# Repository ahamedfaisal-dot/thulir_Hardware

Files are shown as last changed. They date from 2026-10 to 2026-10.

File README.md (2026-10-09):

# THULIR — 3-Stage Cascaded Peltier Temperature Controller

Production-quality firmware for ESP32-S3 driving three cascaded Peltier modules via BTS7960 H-bridge drivers with PID control, TFT HMI, keypad programming, voice announcements, dual servo motors, and comprehensive safety. Cold-side sensing is an I2C SHT3x (temperature + humidity).A companion Python Flask web dashboard streams live telemetry, logs to Excel, and runs on-device ML predictions for seed viability and storage life extension.

---

## Table of Contents

1. [System Architecture](#system-architecture)
2. [Wiring Tables](#wiring-tables)
3. [Power Wiring](#power-wiring)
4. [GPIO Pin Map](#gpio-pin-map)
5. [Required Libraries](#required-libraries)
6. [File Structure](#file-structure)
7. [Process Flow](#process-flow)
8. [PID Tuning Guide](#pid-tuning-guide)
9. [Commissioning Procedure](#commissioning-procedure)
10. [Troubleshooting](#troubleshooting)
11. [Safety Notices](#safety-notices)
12. [Web Dashboard &amp; Seed Intelligence](#web-dashboard--seed-intelligence)

---

## System Architecture

```
┌───────────────────────────────────────────────────────────────────┐
│                         ESP32-S3                                   │
│                                                                    │
│  ┌──────────┐  ┌──────────┐  ┌──────────┐  ┌──────────┐          │
│  │ PID      │  │ Temp     │  │ Recipe   │  │ Safety   │          │
│  │Controller│  │ Manager  │  │ Manager  │  │ Manager  │          │
│  └─────┬────┘  └─────┬────┘  └──────────┘  └─────┬────┘          │
│        │              │                           │                │
│  ┌─────▼────────────────────────────────────────────────┐         │
│  │              Main State Machine                       │         │
│  │   BOOT → IDLE → APPROACH → HOLD → RAMP → COMPLETE   │         │
│  └─────┬────────────────────────────────┬────────┬──────┘         │
│        │                                │        │                 │
│  ┌─────▼────┐  ┌──────────┐  ┌────────▼──┐  ┌──▼──────┐         │
│  │ Peltier  │  │ Display  │  │ Keypad    │  │ Audio   │          │
│  │ Control  │  │ Manager  │  │ Manager   │  │ Manager │          │
│  └─────┬────┘  └─────┬────┘  └─────┬─────┘  └────┬────┘         │
└────────┼──────────────┼─────────────┼──────────────┼──────────────┘
         │              │             │              │
    ┌────▼────┐   ┌─────▼────┐  ┌────▼────┐  ┌─────▼────┐
    │ 3×      │   │ ILI9341  │  │ 4×4     │  │ DFPlayer │
    │ BTS7960 │   │ 320×240  │  │ Keypad  │  │ Mini     │
    └────┬────┘   └──────────┘  └─────────┘  └──────────┘
         │
    ┌────▼────────────────┐
    │ 3× Peltier Modules  │
    │ (Cascaded Stack)    │
    │ BOT → MID → TOP    │
    └─────────────────────┘
```

---

## Wiring Tables

> The table below is the **authoritative, verified-working** pinout as of the
> final hardware bring-up (TFT confirmed working via `Adafruit_ILI9341`).
> It matches `Config.h` exactly — if the two ever disagree, trust `Config.h`
> and update this table.

### Low-Current Logic Connections (3.3V / Signal Level)

| Component | Component Pin | ESP32-S3 GPIO | Notes |
| --- | --- | --- | --- |
| **BTS7960 #1 (Bottom)** | RPWM | GPIO 4 | PWM signal |
| | LPWM | **GND** (hardwired)  | Always LOW — wire directly to GND; no GPIO used |
| | R_EN | **3.3V** (hardwired) | Always HIGH — wire directly to 3.3V; no GPIO used |
| | L_EN | **3.3V** (hardwired) | Always HIGH — wire directly to 3.3V; no GPIO used |
| | VCC | 3.3V | Logic supply |
| | GND | GND | Common ground |
| **BTS7960 #2 (Middle)** | RPWM | GPIO 8 | PWM signal |
| | LPWM | **GND** (hardwired)  | Always LOW — wire directly to GND; no GPIO used |
| | R_EN | **3.3V** (hardwired) | Always HIGH — wire directly to 3.3V; no GPIO used |
| | L_EN | **3.3V** (hardwired) | Always HIGH — wire directly to 3.3V; no GPIO used |
| | VCC | 3.3V | Logic supply |
| | GND | GND | Common ground |
| **BTS7960 #3 (Top)** | RPWM | **GPIO 42** | PWM signal (moved from GPIO12 to free native FSPI SCK) |
| | LPWM | **GND** (hardwired)  | Always LOW — wire directly to GND; no GPIO used |
| | R_EN | **3.3V** (hardwired) | Always HIGH — wire directly to 3.3V; no GPIO used |
| | L_EN | **3.3V** (hardwired) | Always HIGH — wire directly to 3.3V; no GPIO used |
| | VCC | 3.3V | Logic supply |
| | GND | GND | Common ground |
| **SHT3x (Cold side, Temp+Humidity)** | VIN | 3.3V | 2.2–5.5V tolerant sensor, powered at 3.3V here |
| | GND | GND | |
| | SDA | **GPIO 35** | GPIO3 (strapping pin, broke uploads) and GPIO33 (not broken out on this board) were tried first |
| | SCL | **GPIO 36** | Confirmed present and free on this board's actual pinout diagram |
| **DS18B20 (Hot side, optional)** | DATA | GPIO 37 | Not installed by default — set`HOT_SIDE_SENSOR_ENABLED true` in Config.h to use. Moved from GPIO43 — OneWire hung the chip on that pin (ESP32-S3's default UART0 pin) |
| | VCC | 3.3V | |
| | GND | GND | |
| **TFT ILI9341** | SCK | **GPIO 12** | Driven via`Adafruit_ILI9341` + explicit `SPIClass(FSPI)` |
| | MOSI (SDI) | **GPIO 11** | |
| | MISO (SDO) | **GPIO 13** | Used for panel ID readback during bring-up diagnostics |
| | CS | **GPIO 10** | Chip select |
| | DC | **GPIO 9** | Data/Command |
| | RST | **GPIO 14** | Reset |
| | VCC | **5V** | This module needs 5V — 3.3V leaves the onboard regulator without enough headroom to init |
| | GND | GND | |
| | LED | 3.3V | Backlight (always on) |
| **4×4 Keypad** | ROW0 | GPIO 16 | |
| | ROW1 | GPIO 17 | |
| | ROW2 | GPIO 18 | |
| | ROW3 | GPIO 38 | (Moved from 19 — USB) |
| | COL0 | GPIO 20 | |
| | COL1 | GPIO 39 | |
| | COL2 | GPIO 40 | |
| | COL3 | GPIO 41 | |
| **DFPlayer Mini** | RX | GPIO 1 (ESP TX) | 1kΩ series resistor recommended |
| | TX | GPIO 2 (ESP RX) | |
| | VCC | 5V | |
| | GND | GND | |
| **Servo 1** | Signal | GPIO 22 | LEDC ch 3, 50 Hz PWM, 500–2400 µs pulse width |
| | VCC | **5V** | Hobby servos (SG90/MG90S) require 5V — do**not** use 3.3V |
| | GND | GND | |
| **Servo 2** | Signal | GPIO 23 | LEDC ch 4, 50 Hz PWM, 500–2400 µs pulse width |
| | VCC | **5V** | Shared 5V rail with Servo 1 |
| | GND | GND | |

> **BTS7960 LPWM / R_EN / L_EN — all three hardwired (actual build):**
> All six enable/direction pins across the three BTS7960 boards are directly
> wired to fixed rails — no GPIO is used for them:
>
> - **LPWM** → GND (always LOW, enforces unidirectional cooling)
> - **R_EN** → 3.3V (always enabled)
> - **L_EN** → 3.3V (always enabled)
>   Only the three **RPWM** lines (GPIO 4, 8, 42) are controlled by the
>   ESP32. This matches `Config.h` which has no LPWM/R_EN/L_EN `#define`s
>   for these hardwired pins.

### High-Current Power Connections (12V)

| Connection | Wire Gauge | Fuse | Notes |
| --- | --- | --- | --- |
| SMPS 12V → BTS7960#1 B+ | ≥14 AWG | 15A blade | Bottom Peltier (12A max) |
| BTS7960#1 M+ → Bottom Peltier + | ≥14 AWG | — | Observe polarity! |
| BTS7960#1 M− → Bottom Peltier − | ≥14 AWG | — | |
| SMPS 12V → BTS7960#2 B+ | ≥16 AWG | 10A blade | Middle Peltier (6A max)  |
| BTS7960#2 M+ → Middle Peltier + | ≥16 AWG | — | |
| BTS7960#2 M− → Middle Peltier − | ≥16 AWG | — | |
| SMPS 12V → BTS7960#3 B+ | ≥16 AWG | 10A blade | Top Peltier (6A max) |
| BTS7960#3 M+ → Top Peltier + | ≥16 AWG | — | |
| BTS7960#3 M− → Top Peltier − | ≥16 AWG | — | |
| SMPS 12V → 4× Fans | ≥16 AWG | 5A | Hardwired, always on |
| SMPS GND → All BTS7960 B− | ≥12 AWG | — | Star ground recommended  |

---

## Power Wiring

```
12V 30A SMPS
     │
     ├──── [15A Fuse] ──── BTS7960 #1 B+/B− ──── Bottom Peltier (12V/12A)
     │
     ├──── [10A Fuse] ──── BTS7960 #2 B+/B− ──── Middle Peltier (12V/6A)
     │
     ├──── [10A Fuse] ──── BTS7960 #3 B+/B− ──── Top Peltier   (12V/6A)
     │
     ├──── [5A Fuse]  ──── 4× Cooling Fans (hardwired)
     │
     └──── 12V→5V Buck ──── ESP32-S3 5V input
            Converter        (or use USB-C for dev)

    ⚠ CRITICAL GROUND RULES:
    • All BTS7960 B− terminals connect to SMPS GND
    • All BTS7960 logic GND pins connect to ESP32 GND
    • ESP32 GND must have a common reference with SMPS GND
    • Use a star-ground topology to minimize ground loops
    • NEVER route 12V/12A through signal-level PCB traces
```

---

## GPIO Pin Map

See `Config.h` for the authoritative, editable pin definitions.

**ESP32-S3 Pins to Avoid:**

- GPIO 0: Boot strapping pin (download mode) — avoid pull-ups/downs
- GPIO 3: Boot strapping pin (JTAG signal source) — **learned the hard
  way**: this was originally used for the SHT3x's I2C SDA, and its
  external pull-up resistor altered this pin's strap state on every
  reset, breaking `esptool`'s USB download-mode handshake entirely
  ("Wrong boot mode detected (0x4)", uploads failed completely). Avoid
  any pull-up/pull-down on GPIO3.
- GPIO 19: USB D− on DevKitC-1
- GPIO 26–32: Do not exist on ESP32-S3 (internal flash)
- GPIO 33, 34: **Not broken out at all on this ESP32-S3-DevKitC-1 board**
  (confirmed from the board's own pinout diagram — these two pins simply
  don't appear on the header). This module reserves them internally for
  PSRAM. Also tried and abandoned for the SHT3x before settling on 35/36.
- GPIO 35–37: Present on this board's header and genuinely free — the
  fact that the board omits 33/34 but keeps 35-37 confirms this module
  only needs 33/34 for PSRAM. **This firmware uses GPIO 35/36 for the
  SHT3x's SDA/SCL, and GPIO 37 for the optional hot-side DS18B20.**
- GPIO 43, 44: Default UART0 TX/RX. With **USB Mode: "Hardware CDC and
  JTAG"** (as specified below), `Serial` runs over native USB instead of
  UART0, and GPIO44 works fine as a plain GPIO output (used here for
  BTS7960 #3 R_EN) — but **GPIO43 hung the chip when OneWire tried to
  use it** during hot-side sensor bring-up (see `DS18B20_Test/`), likely
  because the ESP32-S3 boot ROM itself still drives GPIO43 for its own
  UART0 boot-log output before the app takes over, regardless of the
  USB Mode setting. Avoid GPIO43 for anything timing-sensitive; the
  optional hot-side sensor now uses GPIO37 instead.
- GPIO 45: Boot strapping pin (VDD_SPI voltage select) — do not use with a
  pull-up/pull-down; pulling it high at boot can select the wrong VDD_SPI
  voltage and break flash access on some modules.
- GPIO 46: Boot strapping pin (ROM boot-log verbosity) — lower risk than
  GPIO0/3/45, but not used by this firmware (freed back up when the SHT3x
  moved to GPIO35/36).

**GPIO Summary for this firmware:**

| GPIO | Function | Direction |
| ---- | --- | --- |
| 1 | DFPlayer RX (ESP TX) | Output |
| 2 | DFPlayer TX (ESP RX) | Input |
| 4 | BTS7960#1 RPWM (Bottom PWM) | Output |
| 8 | BTS7960#2 RPWM (Middle PWM) | Output |
| 9 | TFT DC | Output |
| 10 | TFT CS | Output |
| 11 | TFT MOSI | Output |
| 12 | TFT SCK | Output |
| 13 | TFT MISO | Input |
| 14 | TFT RST | Output |
| 16 | Keypad ROW0 | Output |
| 17 | Keypad ROW1 | Output |
| 18 | Keypad ROW2 | Output |
| 20 | Keypad COL0 | Input |
| 22 | Servo 1 PWM signal | Output |
| 23 | Servo 2 PWM signal | Output |
| 35 | SHT3x SDA | I/O |
| 36 | SHT3x SCL | I/O |
| 38 | Keypad ROW3 | Output |
| 39 | Keypad COL1 | Input |
| 40 | Keypad COL2 | Input |
| 41 | Keypad COL3 | Input |
| 42 | BTS7960#3 RPWM (Top PWM) | Output |
| 43 | DS18B20 hot-side (optional) | I/O |

**Why the TFT uses GPIO 9/10/11/12/13/14:**

- These are the pins proven to actually work with this ILI9341 panel on this
  ESP32-S3 board (verified across two independent working projects, `igem`
  and `sih2026_input`, and by a register-ID readback test in this project).
- **GPIO 11 (MOSI)**: BTS7960 all enable/direction pins are hardwired —
  no GPIO needed for LPWM/R_EN/L_EN, freeing GPIO 11 for TFT MOSI.
- **GPIO 12 (SCK)**: BTS7960 #3 `TOP RPWM` was moved to GPIO 42, freeing
  GPIO 12 for TFT SCK.
- **GPIO 9, 10, 13, 14 (DC/CS/MISO/RST)**: Entirely free since all BTS7960
  enable lines are hardwired to 3.3V/GND; no GPIO pins wasted on them.

---

## Required Libraries

Install via Arduino Library Manager:

| Library | Author | Version | Purpose |
| --- | --- | --- | --- |
| **Adafruit_ILI9341** | Adafruit | ≥1.5 | TFT display driver |
| **Adafruit_GFX_Library** | Adafruit | ≥1.11  | Graphics primitives (required by Adafruit_ILI9341) |
| **Adafruit_SHT31_Library** | Adafruit | ≥2.2 | Cold-side temperature + humidity sensor (I2C) |
| **Adafruit_BusIO** | Adafruit | ≥1.14  | I2C/SPI transport (dependency of Adafruit_SHT31_Library) |
| OneWire | Paul Stoffregen | ≥2.3 | 1-Wire protocol — only needed for the optional hot-side DS18B20 |
| DallasTemperature | Miles Burton | ≥3.9 | DS18B20 driver — only needed for the optional hot-side sensor |
| Keypad | Mark Stanley | ≥3.1 | Matrix keypad |
| DFRobotDFPlayerMini | DFRobot | ≥1.0.5 | Audio player |

> ⚠ **Do not use TFT_eSPI for the display.** It was tried first (it's a
> capable, widely-used library) but on this specific ESP32-S3 board this
> ILI9341 panel never responded to it — confirmed by a register-ID read
> returning `0x00 0x00 0x00` on every attempt, even with correct pins,
> power, and ground. `Adafruit_ILI9341` works perfectly on the exact same
> wiring, so `DisplayManager` uses that instead. No `User_Setup.h` /
> library-folder config file is needed — pins are passed directly in
> `DisplayManager::begin()` (see `Config.h`).

**Board:** ESP32S3 Dev Module (Arduino-ESP32 Core **2.x**)

**Arduino IDE Board Settings:**

- Board: "ESP32S3 Dev Module"
- USB Mode: "Hardware CDC and JTAG" (for Serial Monitor)
- Flash Size: 8MB (or as per your module)
- Partition Scheme: "Default 4MB with spiffs"
- PSRAM: "OPI PSRAM" if your module has R8 suffix, otherwise "Disabled"

---

## File Structure

```
thulir_final/
├── thulir_final.ino      — Main sketch: setup(), loop(), state machine
│                           (also holds TEST_MODE, a build-time switch for
│                           the Adafruit_ILI9341 display-only bring-up test)
├── Config.h              — All GPIO pins, constants, defaults, tunables
├── PIDController.h/cpp   — PID algorithm (anti-windup, derivative-on-measurement)
├── PeltierControl.h/cpp  — BTS7960 driver, LEDC PWM, cascade power distribution
├── TemperatureManager.h/cpp — SHT3x temp+humidity reads (+ optional DS18B20), filtering
├── RecipeManager.h/cpp   — 5-step recipe, NVS persistence
├── KeypadManager.h/cpp   — Non-blocking scan, numeric input FSM
├── DisplayManager.h/cpp  — ILI9341 HMI screens via Adafruit_ILI9341, selective redraw
├── AudioManager.h/cpp    — DFPlayer Mini non-blocking announcements
├── SafetyManager.h/cpp   — Fault detection, emergency stop
├── ServoManager.h/cpp    — Dual servo motor control (open/close on process events)
├── WebManager.h/cpp      — WiFi telemetry (non-blocking HTTP POST)
└── README.md             — This file
```

---

## Process Flow

```
POWER ON
   ↓
SERVO OPEN (both servos open — boot sequence)
   ↓
SELF TEST (sensor, display, audio)
   ↓
IDLE (Home Screen)
   ↓
USER PROGRAMS RECIPE (D → Menu → Program)
   ↓
RECIPE SAVED (#)
   ↓
READY (Menu → Start → Confirm)
   ↓
SENSOR CHECK ──── FAIL ──→ FAULT SCREEN → SERVO OPEN
   ↓ PASS
STEP 1: 25°C
   ↓ approach → confirm (30s in band) → hold (timer)
   ↓ hold complete → SERVO OPEN 15 s → auto-close
STEP 2: 0/15/25°C
   ↓ approach → confirm → hold
   ↓ hold complete → SERVO OPEN 15 s → auto-close
STEP 3: 4°C
   ↓ approach → confirm → hold
   ↓ hold complete → SERVO OPEN 15 s → auto-close
STEP 4: 0/25°C
   ↓ approach → confirm → hold
   ↓ hold complete → SERVO OPEN 15 s → auto-close
STEP 5: RAMP −1°C/min
   ↓ continuous setpoint ramp
−20°C REACHED
   ↓
PROCESS COMPLETE
   ↓
PELTIERS OFF
   ↓
SERVO CLOSE (chamber sealed)
   ↓
IDLE

EMERGENCY STOP / FAULT → PELTIERS OFF → SERVO OPEN (safe egress)
```

---

## PID Tuning Guide

### Initial Conservative Values (Config.h defaults)

```
Kp = 15.0   — Proportional gain
Ki =  0.5   — Integral gain
Kd =  5.0   — Derivative gain
```

> ⚠ These are PLACEHOLDER values. You MUST tune them experimentally.

> **Integral separation:** the integral term only accumulates while
> `|actualTemp - setpoint|` is within `PID_INTEGRAL_ZONE_DEG` (default
> 3.0°C, in Config.h). This prevents windup from building during a long
> approach from far away (e.g. ambient temperature down to a step's
> target) — without it, output can stay pegged near-max well after
> crossing the setpoint, because a large accumulated integral bleeds off
> very slowly against a now-small error. If you still see this after
> tuning Kp/Ki/Kd, try narrowing `PID_INTEGRAL_ZONE_DEG`.

### Tuning Procedure

1. **Open the PID screen** (Menu → PID TUNE)
2. **Start with P-only control**: Set Ki=0, Kd=0
3. **Set a target** (e.g., 10°C) and start the process
4. **Increase Kp** until you see slight oscillation around the target
5. **Reduce Kp by ~30%** from the oscillation point
6. **Add Ki** slowly (start at 0.1) to eliminate steady-state error
7. **Add Kd** (start at 2.0) to damp overshoot
8. **Save to NVS** when satisfied (press # on PID screen)

### Key Observations

- **Large overshoot**: Reduce Kp, increase Kd
- **Slow approach**: Increase Kp
- **Steady-state offset**: Increase Ki (small increments!)
- **Oscillation**: Reduce Kp and Ki, increase Kd
- **Ramp lag (Step 5)**: System may need higher Kp for aggressive ramp tracking

### Tuning for Different Temperature Ranges

The Peltier stack behaves differently at different temperatures:

- Near ambient (25°C): Low power needed, PID may need lower gains
- Near 0°C: Moderate power, standard gains
- Below −10°C: High power, COP drops, may need aggressive gains

Consider tuning at your most critical operating point (likely Step 5 ramp).

---

## Commissioning Procedure

### Phase 1: Basic Hardware Verification

| # | Step | Procedure | Expected Result |
| - | --- | --- | --- |
| 1 | Test ESP32-S3 | Upload blink sketch, check Serial Monitor | Serial output at 115200 baud |
| 2 | Test TFT | Upload THULIR firmware, check for boot screen | "THULIR Initializing..." on display |
| 3 | Test Keypad | Press keys on HOME screen, go to Menu | Keys register, menu navigates |
| 4 | Test SHT3x | Check boot log for sensor detection | "SHT3x initialized" with a plausible temp/RH pair |
| 5 | Test DFPlayer | Menu → Test → 4 (Test DFPlayer) | "System starting" audio plays |

### Phase 2: Motor Driver Verification (No Peltier Connected)

| # | Step | Procedure | Expected Result |
| - | --- | --- | --- |
| 6 | Test Fans | Power on SMPS, check fans spin | 4 fans running |
| 7 | BTS7960#1 | Disconnect Peltier. Test Mode → 5 (Bottom). Set 10%, press # | Measure PWM on M+/M− with oscilloscope or multimeter |
| 8 | BTS7960#2 | Test Mode → 6 (Middle). Set 10%, press # | PWM output on middle BTS7960 |
| 9 | BTS7960#3 | Test Mode → 7 (Top). Set 10%, press # | PWM output on top BTS7960 |

### Phase 3: Individual Peltier Testing

> ⚠ Connect ONE Peltier at a time. Use LOW PWM (10-20%).

| #  | Step | Procedure | Expected Result |
| -- | --- | --- | --- |
| 10 | Bottom Peltier | Connect, Test Mode → 5, 10% PWM | Cold side gets slightly cool, hot side warm |
| 11 | Middle Peltier | Connect, Test Mode → 6, 10% PWM | Slight cooling effect |
| 12 | Top Peltier | Connect, Test Mode → 7, 10% PWM | Slight cooling at top |
| 13 | Bottom only | Run Step 1 (25°C) with only bottom connected | PID controls to 25°C |

### Phase 4: Cascade Testing

| #  | Step | Procedure | Expected Result |
| -- | --- | --- | --- |
| 14 | Middle + Bottom | Connect bottom and middle, test at low power | Enhanced cooling vs. bottom alone |
| 15 | Full cascade | Connect all three, test at low power | Further cooling improvement |
| 16 | Temperature response | Plot temperature vs. time at various setpoints | Characterize thermal response |

### Phase 5: PID Tuning

| #  | Step | Procedure | Expected Result |
| -- | --- | --- | --- |
| 17 | Characterize | Run open-loop tests at various PWM levels | Understand thermal time constants |
| 18 | Tune PID | Follow PID Tuning Guide above | Stable temperature control |

### Phase 6: Process Testing

| #  | Step | Procedure | Expected Result |
| -- | --- | --- | --- |
| 19 | Test Step 1 | Run with default recipe, monitor only Step 1 | Holds 25°C for programmed time |
| 20 | Test Step 2 | Allow Step 2 to run (15°C default) | Approaches and holds 15°C |
| 21 | Test Step 3 | Test 4°C target | Stable hold at 4°C |
| 22 | Test Step 4 | Test 0°C target | Stable hold at 0°C |
| 23 | Test Step 5 | Full ramp test to −20°C | Smooth ramp at −1°C/min |

### Phase 7: Safety Testing

| #  | Step | Procedure | Expected Result |
| -- | --- | --- | --- |
| 24 | Emergency Stop | Press C → D during active process | Peltiers off, EMERGENCY STOP screen  |
| 25 | Sensor disconnect | Unplug SHT3x during operation | FAULT screen, Peltiers off |
| 26 | Power restart | Power cycle during operation | System boots to IDLE, no auto-resume |

---

## Troubleshooting

### Display Issues

| Problem | Possible Cause | Solution |
| --- | --- | --- |
| No backlight at all | Display VCC/LED not powered | Confirm VCC is on**5V** and LED is on 3.3V — a floating/unpowered rail gives a totally dark panel |
| Backlight on, screen white | Panel powered but not initializing | Verify wiring against the table above; run the`TEST_MODE 2` bring-up test in `thulir_final.ino` and check `[TEST] Display ID bytes` in Serial — `0x00 0x00 0x00` means the panel isn't responding at all |
| Backlight on, screen black (static, never changes) | Same as above — panel at its power-up default, not receiving commands | Same as above |
| PSRAM pin conflict | Using GPIO 33/34 for other signals | This board doesn't even break these out — confirmed unusable regardless. GPIO 35–37 are confirmed free and safe on this board |
| Garbled display | Wrong rotation | Change`setRotation()` in `DisplayManager::begin()` |
| Wrong colors | RGB vs BGR byte order | Adafruit_ILI9341 defaults to RGB; check the panel datasheet if colors look swapped |
| Flickering | Full redraw too often | Increase`DISPLAY_UPDATE_INTERVAL` in Config.h |
| Turns white whenever the 12V system is powered (even at 0% PWM, idle) | Noise/ground-bounce from the SMPS itself (not specifically PWM switching) glitching the RST line — a real hardware reset of the panel, not a code bug | Firmware now self-heals this automatically (see watchdog note below) within ~12-16s. For a permanent fix: strengthen the common ground bond between the ESP32 and the 12V/SMPS domain (single short, thick, direct wire — not a long/daisy-chained one), add a 100nF-1µF capacitor from RST to GND right at the display, route SPI/RST wiring away from the 12V wiring, and add bulk capacitance directly on the SMPS output |

> This project moved from `TFT_eSPI` to `Adafruit_ILI9341` after `TFT_eSPI`
> never got a response from this specific panel on this specific ESP32-S3
> board (confirmed by reading the panel's ID register and getting all
> zeros, across many verified-correct wiring/power/pin configurations).
> If a display "should" work per every check above but still doesn't,
> trying the other driver library is a legitimate next step — see
> `TEST_MODE 2` in `thulir_final.ino` for a ready-made isolated test.

> **Display watchdog:** only active while a process is actually running
> (`STATE_STEP_APPROACH`/`STEP_HOLD`/`STEP5_RAMP`/`STEP_TRANSITION`) —
> that's when the 12V system is doing real work and the display actually
> matters, so there's no reason to poll it while idle. Once a process
> starts, `thulir_final.ino`'s main loop checks the panel's health every
> 4s (`DISPLAY_HEALTH_CHECK_INTERVAL_MS`) via
> `DisplayManager::isAlive()`, which itself reads the panel's ID
> registers twice (5ms apart) before reporting a failure — since that
> readback travels over the same noisy SPI/MISO lines as everything
> else, a single bad read can be the *check* glitching, not the panel,
> and this filters that out. After 3 consecutive failed checks
> (`DISPLAY_HEALTH_FAIL_THRESHOLD`, ~12-16s), it silently calls
> `displayMgr.begin(false)` (re-init without the splash screen/delay) and
> redraws the current screen — recovering automatically from a real
> RST-glitch reset instead of needing a manual reboot, without
> over-triggering on routine noise. This is a mitigation, not a fix for
> the underlying noise —
> still do the hardware fixes above if this triggers often.

### Temperature / Humidity Sensor Issues (SHT3x)

| Problem | Possible Cause | Solution |
| --- | --- | --- |
| "SHT3x not found" | Bad wiring or wrong address | Check VIN/GND/SDA/SCL; confirm`SHT3X_I2C_ADDR` matches the board (0x44 default, 0x45 if ADDR pin high) |
| Reads NaN / invalid | I2C bus glitch or bad wiring | Check SDA/SCL continuity and pull-ups; the code already rejects NaN reads |
| Humidity shows "RH:--" | Same I2C failure as above | Fix the I2C connection — humidity uses the same read as temperature |
| Noisy readings | Electrical interference | Keep I2C wires short and away from the 12A/6A/6A power wiring |
| Sudden jump rejected | Real glitch, or threshold too tight | See`TEMP_INVALID_THRESH` in Config.h if legitimate fast changes are being rejected |

### Optional Hot-Side DS18B20 Issues

| Problem | Possible Cause | Solution |
| --- | --- | --- |
| "Sensor not found" | Bad wiring, or`HOT_SIDE_SENSOR_ENABLED` still false | Check DATA/VCC/GND, verify 4.7kΩ pull-up, flip the flag in Config.h |
| Reads −127°C | Disconnected sensor | Check connections |
| Reads 85°C | Power-on reset value | Sensor not initializing — check power |

### Peltier / BTS7960 Issues

| Problem | Possible Cause | Solution |
| --- | --- | --- |
| No cooling effect | Wrong Peltier polarity | Swap + and − on Peltier (cool/hot sides flip) |
| BTS7960 overheating | Over-current | Check fuses, reduce PWM max limits |
| Audible buzzing | PWM frequency too low  | Increase PWM_FREQUENCY in Config.h |
| Erratic PWM | GPIO conflict | Check pin assignments, avoid strapping pins |
| Peltier hot on both sides | LPWM not LOW | Verify LPWM pin is wired and held LOW |

### DFPlayer Issues

| Problem | Possible Cause | Solution |
| --- | --- | --- |
| "Not detected" | TX/RX swapped | ESP TX → DFPlayer RX (and vice versa) |
| No audio | Volume too low | Increase DFPLAYER_VOLUME in Config.h |
| Wrong track plays | File numbering | Files must be /mp3/0001.mp3 through /mp3/0012.mp3 |
| Distorted audio | Power supply noise | Add 1000µF capacitor on DFPlayer VCC |

### Keypad Issues

| Problem | Possible Cause | Solution |
| --- | --- | --- |
| Keys not registering | Wrong pin mapping | Verify ROW/COL pins in Config.h |
| Multiple keys ghost  | Missing diodes | Use a keypad with built-in diodes |
| Slow response | Debounce too high | Reduce debounce time in KeypadManager.cpp |

### PID Control Issues

| Problem | Possible Cause | Solution |
| --- | --- | --- |
| Oscillation | Kp too high | Reduce Kp by 30-50% |
| Slow approach | Kp too low | Increase Kp gradually |
| Steady offset | Ki too low | Increase Ki in small steps |
| Overshoot | Kd too low, Ki too high | Increase Kd, decrease Ki |
| Ramp lag (Step 5) | Insufficient cooling power | Normal at very low temps (COP drops) |

---

## Safety Notices

### ⚠ Electrical Safety

- **Fuses are mandatory.** Without fuses, a short circuit can cause fire.
- **Use adequate wire gauge.** 12A through thin wire = fire hazard.
- **Install a physical emergency cutoff.** Software alone is not sufficient.
- **Common ground is critical.** Floating grounds cause erratic BTS7960 behavior.
- **Never power ESP32-S3 from 12V directly.** Use a regulated 5V/3.3V supply.

### ⚠ Thermal Safety

- **Hot-side monitoring is strongly recommended.** The bottom Peltier's hot side can exceed 80°C under load. Set `HOT_SIDE_SENSOR_ENABLED = true` in Config.h and add a DS18B20 to the heatsink.
- **Adequate heatsink is critical.** Without proper heat dissipation, Peltier efficiency drops and thermal runaway is possible.
- **Use thermal interface material (TIM)** between all Peltier surfaces and heatsinks.
- **Never run full cascade at 100% PWM** without verified thermal management.

### ⚠ Software Limitations

- The ESP32 **cannot detect overcurrent** without external current sensors.
- Software PWM limits are a **secondary safeguard only**.
- The firmware **does not** automatically resume after power failure.
- The firmware **does not** provide galvanic isolation or true fail-safe shutdown.

---

## DFPlayer Audio File Map

Place these MP3 files on the microSD card in the `/mp3/` directory:

```
/mp3/0001.mp3 — "Step One — Starting" (AUDIO_STEP1)
/mp3/0002.mp3 — "Step Two — Cooling" (AUDIO_STEP2)
/mp3/0003.mp3 — "Step Three — Deep Freeze" (AUDIO_STEP3)
/mp3/0004.mp3 — "Step Four — Stabilizing" (AUDIO_STEP4)
/mp3/0005.mp3 — "Warning — Temperature Dropping" (AUDIO_EMERGENCY)
/mp3/0006.mp3 — "Process Completed Successfully" (AUDIO_COMPLETE)
/mp3/0007.mp3 — "Welcome to THULIR CryoLab" (AUDIO_WELCOME)
/mp3/0008.mp3 — "Enter Step One Duration" (AUDIO_WIZARD_1)
/mp3/0009.mp3 — "Enter Step Two Duration" (AUDIO_WIZARD_2)
/mp3/0010.mp3 — "Enter Step Three Duration" (AUDIO_WIZARD_3)
/mp3/0011.mp3 — "Enter Step Four Duration" (AUDIO_WIZARD_4)
```

File numbering matches `AudioTrack` enum in `hmi_audio.h` and `Config.h`.

---

## Web Dashboard & Seed Intelligence

The `thulir_dashboard/` folder contains a Python Flask server that receives live telemetry from the ESP32, displays it in a browser, and runs ML-based seed viability predictions.

### Quick Start

```bash
cd thulir_dashboard
pip install -r requirements.txt
python app.py
# Open http://localhost:5000  (or http://<PC-LAN-IP>:5000 from any device on the same WiFi)
```

- Set `WEB_SERVER_HOST` in `Config.h` to your PC's LAN IP before flashing.
- The ESP32 POSTs telemetry every 2 s (`WEB_POST_INTERVAL_MS`). The dashboard updates in real time via WebSocket.

### Live Monitoring

- **Pages** — Home, Run Monitor, Protocols, Run History, User Guide, Settings (CryoAxis / THULIR theme).
- **Remote control** — START (sends the protocol recipe) and ABORT from the dashboard; the device acknowledges every command (see `thulir_dashboard/README.md`). Disable with `WEB_REMOTE_CONTROL_ENABLED` in `Config.h`.
- **Real-time temperature chart** — Actual vs the planned protocol profile with tolerance band.
- **Peltier PWM bars** — PID demand, Bottom, Middle, Top stage outputs updated live.
- **Process timing** — Elapsed, Remaining hold time, Device uptime.
- **Status strip** — State, Step, Error code, Sensor validity, Ramp lag, Servo status — all live.
- **ETA to Target** — Linear-regression estimate of time remaining to reach the current target temperature.
- **Auto-reconnect** — Dashboard detects ESP32 dropout (no data >10 s, configurable) and shows OFFLINE; reconnects automatically.
- **Run logging & Excel export** — Every run (measurements, events, alerts) is stored in SQLite and exportable per run.

### Seed Intelligence — ML Predictions

All predictions run server-side in pure Python (no ML frameworks needed).

| Prediction | Method | Key Insight |
| --- | --- | --- |
| **Seed Viability Score** (0–100) | Weighted composite of temp stability + protocol adherence + humidity | Higher = better seed condition during storage |
| **Germination Rate Estimate** (%) | Viability × 0.95, penalised for temps > −10°C | Predicts post-storage germination success |
| **Life Extension** (years + ×factor) | **Q10 rule** — biological reaction rate halves per 10°C drop | At −20°C vs 25°C ambient: ~22× longer life |
| **Temperature Stability Index** (0–100) | Rolling standard deviation → mapped score | 100 = rock-steady; drops sharply with oscillation |
| **Dew Point** (°C) | Magnus formula from temp + RH | Flags condensation risk when dew point approaches surface temp |
| **Process Quality Score** (0–100) | Mean absolute PID error over rolling window | Measures how tightly the firmware tracks the setpoint |
| **Protocol Adherence** (%) | Cumulative fraction of active ticks within ±0.5°C | Tracks long-term compliance with the temperature profile |

- Scores are colour-coded: **green ≥ 80**, **amber 55–79**, **red < 55**.
- The **Predicted Viable Until** year is computed from baseline shelf life (2 yr at ambient) × Q10 extension factor.
- ML values are shown on the Run Monitor page and available at `/api/predict`.
- Standalone predictions available at `/api/predict` (JSON endpoint).

### Environmental Analysis

- **Condensation Risk** — LOW / MODERATE / HIGH based on dew-point margin vs surface temp.
- **Advisory notes** — Automatic warnings if humidity > 25% or temperature above optimal storage range.
- **Stability + Quality history chart** — Second Chart.js chart tracking both scores over the session.

### Servo Motor Events (reflected on dashboard)

- **OPEN** shown when both servos open (power-on, step completion, fault/stop).
- **CLOSED** shown when servos close (process complete, 15 s step-open window expired).

### API Endpoints

| Endpoint | Method | Description |
| --- | --- | --- |
| `/` | GET | Live dashboard UI |
| `/api/data` | POST | ESP32 telemetry receiver |
| `/api/latest`  | GET | Last received telemetry (JSON) |
| `/api/predict` | GET | Latest ML predictions only (JSON) |
| `/api/export`  | GET | Excel export of the latest run |
| `/api/runs`, `/api/runs/<id>/export` | GET | Run history / per-run Excel |
| `/api/protocols` | GET/POST/PUT/DELETE | Protocol management |
| `/api/command` | POST | Queue START / ABORT for the device |

---

## License

This firmware is provided as-is for the THULIR project.
Use at your own risk. Always follow proper electrical and thermal safety practices.

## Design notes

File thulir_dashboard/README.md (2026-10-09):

# CryoAxis / THULIR Process Monitor

Flask + WebSocket dashboard for the THULIR cryopreservation controller.
The ESP32 firmware POSTs telemetry to `/api/data`; the dashboard derives the run
lifecycle from the device state, logs every run to SQLite, and exports runs to Excel.

## Run

```bash
cd thulir_final/thulir_dashboard
pip install -r requirements.txt
python app.py
```

Open http://localhost:5000 (or `http://<PC-LAN-IP>:5000` from another device on the same WiFi).
Point the firmware at this PC in `Config.h` (`WEB_SERVER_HOST`, `WEB_SERVER_PORT`).

## Pages
Home · Run Monitor · Protocols · Run History · User Guide · Settings

## Data (`data/cryoaxis.db`, SQLite)
Protocols (versioned), runs, per-reading measurements, events, alerts, settings.
Override the location with the `THULIR_DB` environment variable.
Export any run: Run History → Excel, or Run Monitor → Export to Excel.
(`data/telemetry.xlsx` is the old log from the previous dashboard; it is no longer written.)

## Remote control (dashboard -> device)
The server attaches a pending command to the reply of the device's telemetry POST; the firmware
runs it through the same code as the keypad and reports an acknowledgement in its next telemetry
packet (`ackId/ackOk/ackMsg`). The dashboard only says "success" once that ack arrives
(15 s timeout, cancelled if the device reboots).

- **START** sends the protocol's recipe (4 hold times + step 2/4 temperatures). The device applies it in RAM
  only (the recipe saved on the keypad is not overwritten), then runs its normal recipe validation and
  pre-start safety check. Refused if the operator is in a keypad menu, or the device is not idle.
- **ABORT** triggers the same emergency stop as the keypad (also opens the servos).
- **PAUSE / RESUME** are not supported by the firmware and stay disabled.
- Only device-compatible protocols can run: steps 1-4 are holds (step 1 = 25 °C, step 2 = 0/15/25 °C,
  step 3 = 4 °C, step 4 = 0/25 °C, whole minutes 1-999) and step 5 is the ramp to -20 °C at -1 °C/min.
- Optional safety: set the `THULIR_CONTROL_PIN` environment variable to require a PIN for START.
- Disable on the device with `WEB_REMOTE_CONTROL_ENABLED false` in `Config.h`.
- The server has no login: anyone who can open the dashboard can press ABORT/START. Keep it on a trusted LAN.

## Other limitations
- Automated pipetting is a static "Not Implemented" placeholder card only.
- User guide PDF: drop it at `static/docs/user_guide.pdf` to enable the download.
- Hardware speaker language cannot be changed from software; language setting affects browser audio only.
- Chart.js / Socket.IO load from a CDN (needs internet on the viewing device; page falls back to polling).

## Tests
```bash
python tests/test_backend.py          # software tests on synthetic telemetry, isolated temp DB
python tests/feed_synthetic.py 120    # synthetic feeder for manual UI testing only
```

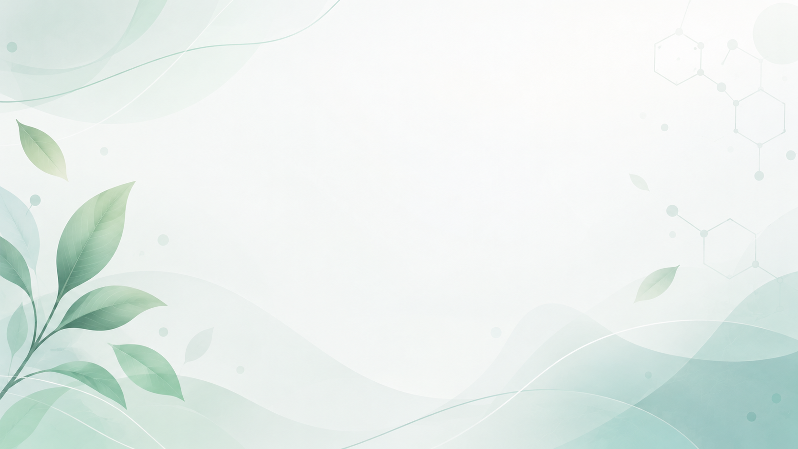
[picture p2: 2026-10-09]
thulir_dashboard/bg_image/thulirbg.png

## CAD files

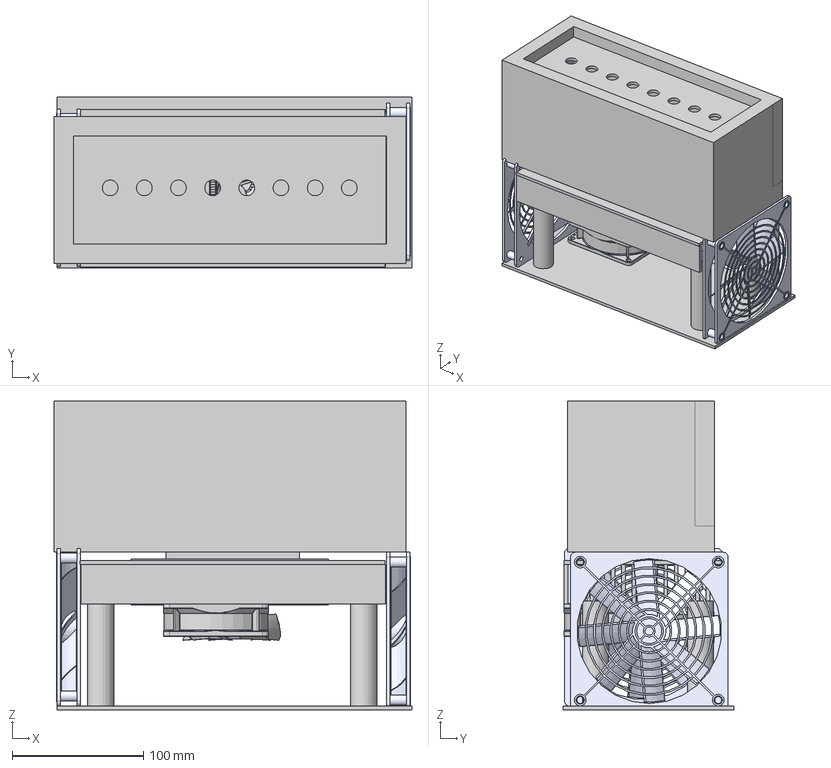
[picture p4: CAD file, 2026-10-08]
3d model/Cryo Unit.step
272.4 x 130.0 x 235.0 mm

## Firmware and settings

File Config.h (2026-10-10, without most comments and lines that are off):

#pragma once
#include <Arduino.h>
#define FW_VERSION_MAJOR  1
#define FW_VERSION_MINOR  0
#define FW_VERSION_PATCH  0
#define FW_VERSION_STR    "1.0.0"
#define FW_NAME           "THULIR"
#define DEBUG_ENABLED           true    // Serial debug output
#define DEBUG_BAUD              115200
#define SERIAL_PRINT_INTERVAL   2000   // ms between debug prints
#define HOT_SIDE_SENSOR_ENABLED false
#define HOT_SIDE_MAX_TEMP       75.0f  // °C — shut down Peltiers above this
#define HOT_SIDE_RECOVERY_TEMP  50.0f  // °C — allow restart below this
#define WEB_DASHBOARD_ENABLED   true
#define WIFI_SSID          "SEMINAR_HALL"
#define WIFI_PASSWORD      "B109#rec"
#define WEB_SERVER_HOST    "172.16.13.124"   // <-- CHANGE to your PC's IP
#define WEB_SERVER_PORT    5000
#define WEB_SERVER_PATH    "/api/data"
#define WEB_POST_INTERVAL_MS   2000    // How often to POST telemetry
#define WEB_WIFI_RETRY_MS      10000   // Retry WiFi connect if dropped
#define WEB_REMOTE_CONTROL_ENABLED true
#define COLDSIDE_SANITY_MAX_TEMP 45.0f  // °C
#define BOTTOM_RPWM_PIN    8    // PWM signal → BTS7960 RPWM (module the BOTTOM Peltier is plugged into)
#define BOTTOM_LPWM_PIN    255  // not used — LPWM hardwired to GND (255 = skip; GPIO5 now used by DS18B20)
#define BOTTOM_REN_PIN     6    // retained for code compat (pin not used — R_EN hardwired to 3.3V)
#define BOTTOM_LEN_PIN     7    // retained for code compat (pin not used — L_EN hardwired to 3.3V)
#define MIDDLE_RPWM_PIN    4    // swapped with BOTTOM — see note above
#define MIDDLE_LPWM_PIN    47   // retained for code compat (pin not used — LPWM hardwired to GND)
#define MIDDLE_REN_PIN     48   // retained for code compat (pin not used — R_EN hardwired to 3.3V)
#define TOP_RPWM_PIN       42   // Moved from GPIO12 — freed for TFT native FSPI CLK
#define TOP_LPWM_PIN       21   // retained for code compat (pin not used — LPWM hardwired to GND)
#define TOP_REN_PIN        44   // retained for code compat (pin not used — R_EN hardwired to 3.3V)
#define TOP_LEN_PIN        255  // not used — L_EN hardwired to 3.3V (255 = skip; GPIO15 now used by DS18B20)
#define SHT3X_SDA_PIN      35
#define SHT3X_SCL_PIN      36
#define SHT3X_I2C_ADDR     0x44   // Default SHT3x address (0x45 if ADDR pin high)
#define DS18B20_HOT_PIN    37   // Hot-side sensor (optional, disabled)
#define COLD_SENSOR_DS18B20   true
#define DS18B20_COLD_PIN      5
#define COLD_DS_RESOLUTION    11     // bits: 11 = 0.125°C, 375 ms conversion
#define COLD_DS_CONVERSION_MS 400    // wait before reading a conversion
#define TFT_CS_PIN         10
#define TFT_DC_PIN         9
#define TFT_RST_PIN        14
#define TFT_MOSI_PIN       11
#define TFT_SCK_PIN        12
#define TFT_MISO_PIN       13
#define KP_ROW0_PIN        16
#define KP_ROW1_PIN        17
#define KP_ROW2_PIN        18
#define KP_ROW3_PIN        38   // Moved from 19 (USB on DevKitC)
#define KP_COL0_PIN        20   // Safe if USB-OTG not used
#define KP_COL1_PIN        39
#define KP_COL2_PIN        40
#define KP_COL3_PIN        41
#define DFPLAYER_TX_PIN    1    // ESP32 UART1 TX → DFPlayer RX
#define DFPLAYER_RX_PIN    2    // DFPlayer TX → ESP32 UART1 RX
#define PWM_FREQUENCY      5000     // Hz
#define PWM_RESOLUTION     10       // bits → 0–1023 duty range
#define PWM_MAX_DUTY       ((1 << PWM_RESOLUTION) - 1)  // 1023
#define BOTTOM_POWER_RATIO  1.00f   // 100% (11.43 V measured)
#define MIDDLE_POWER_RATIO  1.00f   // 6.10 V rail
#define TOP_POWER_RATIO     1.00f   // 2.45 V rail
#define BOTTOM_MAX_PWM_PCT  100.0f  // % of full duty
#define MIDDLE_MAX_PWM_PCT  100.0f   // rail is already 6.1 V
#define TOP_MAX_PWM_PCT     100.0f   // rail is already 2.45 V
#define MIN_PWM_THRESHOLD    0.0f   // % — set >0 if needed
#define DEFAULT_KP            8.0f
#define DEFAULT_KI            0.035f
#define DEFAULT_KD          120.0f
#define PID_SAMPLE_TIME_MS    500   // PID compute interval (ms)
#define PID_OUTPUT_MIN        0.0f
#define PID_OUTPUT_MAX      100.0f
#define APPROACH_KP           8.0f
#define APPROACH_KI           0.035f
#define APPROACH_KD         120.0f
#define APPROACH_INTEGRAL_ZONE  5.0f   // °C — integral only inside this band
#define RAMP_KP              10.0f
#define RAMP_KI               0.05f
#define RAMP_KD             120.0f
#define RAMP_INTEGRAL_ZONE    3.0f    // °C
#define PID_FF_AMBIENT_REF    25.0f   // °C — reference point (no cooling needed)
#define PID_FF_MAX_COOL      -27.0f   // °C — (legacy, no longer used by the FF map)
#define PID_FF_DELTA_MAX      48.0f   // °C
#define PID_FF_MAX_PCT        92.0f   // % — cap to leave headroom for PID correction
#define PID_OUTPUT_RATE_LIMIT  15.0f  // %/second (0.0 = disabled)
#define SHT3X_READ_INTERVAL_MS    500    // How often to read the SHT3x
#define TEMP_CONVERSION_MS       750    // DS18B20 12-bit conversion time —
#define TEMP_FILTER_SAMPLES        5    // Moving-average window
#define TEMP_SENSOR_MIN        -40.0f   // Valid range low
#define TEMP_SENSOR_MAX         85.0f   // Valid range high
#define TEMP_ERROR_VALUE      -127.0f   // DS18B20 disconnect code (hot-side)
#define TEMP_INVALID_THRESH     0.5f    // Reject jump > this per sample
#define HUMIDITY_SENSOR_MIN      0.0f   // Valid RH% range low
#define HUMIDITY_SENSOR_MAX    100.0f   // Valid RH% range high
#define TEMP_CALIBRATION_OFFSET 0.0f    // Default cal offset
#define TEMP_CAL_OFFSET_MAX     5.0f    // Warn if |offset| exceeds this
#define TARGET_TOLERANCE        0.5f    // °C
#define TARGET_CONFIRM_TIME_MS  30000   // 30 seconds
#define HOLD_TIMER_PAUSE_ON_DEVIATION  true
#define RAMP_RATE_DEFAULT      -1.0f    // °C per minute
#define RAMP_FINAL_TARGET      -20.0f   // °C
#define RAMP_UPDATE_INTERVAL_MS  100    // Setpoint update rate
#define RAMP_LAG_THRESHOLD      2.0f    // °C behind setpoint → warning
#define RAMP_MAX_DURATION_MS   (150UL * 60000UL)   // 150 minutes
#define DEFAULT_STEP1_TEMP      25.0f
#define DEFAULT_STEP1_TIME      30      // minutes
#define DEFAULT_STEP2_TEMP      15.0f   // User-selectable: 0/15/25
#define DEFAULT_STEP2_TIME      30
#define DEFAULT_STEP3_TEMP       4.0f
#define DEFAULT_STEP3_TIME      20
#define DEFAULT_STEP4_TEMP       0.0f   // User-selectable: 0/25
#define DEFAULT_STEP4_TIME      20
#define DISPLAY_UPDATE_INTERVAL   500
#define KEYPAD_SCAN_INTERVAL       50
#define SAFETY_CHECK_INTERVAL     500
#define AUDIO_MIN_INTERVAL       2000   // Min gap between announcements
#define FAN_CONTROL_ENABLED  false
#define SERVO1_PIN            22   // Servo 1 PWM signal
#define SERVO2_PIN            23   // Servo 2 PWM signal
#define SERVO_OPEN_ANGLE      90   // degrees — lid/door fully open
#define SERVO_CLOSED_ANGLE     0   // degrees — lid/door fully closed
#define SERVO_STEP_OPEN_MS  15000  // 15 seconds
#define SERVO1_LEDC_CHANNEL    4
#define SERVO2_LEDC_CHANNEL    5
#define SERVO_LEDC_FREQ        50   // Hz (standard hobby servo)
#define SERVO_LEDC_RES         16   // bits → 0–65535 duty range
#define COLOR_BG               0x0944  // Deep forest green (dashboard header tone, darkened for TFT contrast) #0E2B22
#define COLOR_HEADER_BG        0x1247  // Dashboard header green #174A3A
#define COLOR_TEXT_PRIMARY     0xFFFF  // White #FFFFFF
#define COLOR_TEXT_SECONDARY   0xDF5C  // Pale green-white (dashboard card border) #DDE9E3
#define COLOR_TEXT_DIM         0x8D74  // Muted sage #8FAEA1
#define COLOR_TEMP_ACTUAL      0x4DB6  // Dashboard actual-temperature teal #4FB6B2
#define COLOR_TEMP_TARGET      0xBF3A  // Light mint (target line; dashboard dark green is unreadable on a dark TFT) #BFE6D1
#define COLOR_STATUS_OK        0x5E31  // Bright green (dashboard success #3E8B63, lightened for contrast) #5CC48A
#define COLOR_STATUS_WARN      0xDCC6  // Dashboard warning amber #D99A35
#define COLOR_STATUS_ERR       0xE32C  // Dashboard error red (lightened for contrast) #E06666
#define COLOR_BAR_FILL         0x4DB6  // Dashboard progress-bar teal #4FB6B2
#define COLOR_BAR_BG           0x1A26  // Dark green bar track #1D4437
#define COLOR_DIVIDER          0x2B0A  // Green separator line #2E6350
#define COLOR_HIGHLIGHT        0x4DB6  // Dashboard active/selected teal #4FB6B2
#define COLOR_MENU_SEL_BG      0x1247  // Dashboard header green selection bg #174A3A
#include "hmi_audio.h"
#define AUDIO_SYSTEM_START     AUDIO_WELCOME
#define AUDIO_EMERGENCY_STOP   AUDIO_EMERGENCY
#define AUDIO_SENSOR_ERROR     AUDIO_EMERGENCY
#define AUDIO_OVER_TEMP        AUDIO_EMERGENCY
#define DFPLAYER_VOLUME        25      // 0–30
#define NVS_NAMESPACE          "thulir"
#define NVS_KEY_S1_TIME        "s1_time"
#define NVS_KEY_S2_TEMP        "s2_temp"
#define NVS_KEY_S2_TIME        "s2_time"
#define NVS_KEY_S3_TIME        "s3_time"
#define NVS_KEY_S4_TEMP        "s4_temp"
#define NVS_KEY_S4_TIME        "s4_time"
#define NVS_KEY_KP             "kp"
#define NVS_KEY_KI             "ki"
#define NVS_KEY_KD             "kd"
#define NVS_KEY_CAL_OFFSET     "cal_off"
#define NVS_KEY_BOTTOM_RATIO   "bot_ratio"
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

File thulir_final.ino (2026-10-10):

/*
 * ============================================================
 *  THULIR — 3-Stage Cascaded Peltier Temperature Controller
 *  thulir_final.ino — Main Sketch
 * ============================================================
 *
 *  PROCESS FLOW:
 *    POWER ON → SELF TEST → IDLE
 *    → USER PROGRAMS RECIPE → RECIPE CONFIRMED → READY
 *    → START → SENSOR CHECK → STEP 1 (25°C, hold)
 *    → STEP 2 (0/15/25°C, hold)
 *    → STEP 3 (4°C, hold)
 *    → STEP 4 (0/25°C, hold)
 *    → STEP 5 (ramp −1°C/min to −20°C)
 *    → PROCESS COMPLETE → PELTIERS OFF → IDLE
 *
 *  STATE MACHINE:
 *    STATE_BOOT           — Hardware initialization & self-test
 *    STATE_IDLE           — Waiting for user, home screen
 *    STATE_PROGRAMMING    — Editing recipe via keypad
 *    STATE_READY          — Recipe confirmed, awaiting START
 *    STATE_STEP_APPROACH  — Cooling/heating to step target
 *    STATE_STEP_HOLD      — Target reached, holding for timer
 *    STATE_STEP_TRANSITION— Moving to next step
 *    STATE_STEP5_RAMP     — Ramping −1°C/min to −20°C
 *    STATE_COMPLETE       — Process finished
 *    STATE_STOPPED        — Emergency stop
 *    STATE_FAULT          — Fault detected
 *    STATE_TEST_MODE      — Component testing
 *
 *  POWER FAILURE BEHAVIOR:
 *    On reboot, all outputs start at 0%. The system does NOT
 *    automatically resume a partially completed recipe. The user
 *    must manually restart.
 *
 * ============================================================
 */

#include "Config.h"
#include "PIDController.h"
#include "PeltierControl.h"
#include "TemperatureManager.h"
#include "RecipeManager.h"
#include "KeypadManager.h"
#include "DisplayManager.h"
#include "AudioManager.h"
#include "SafetyManager.h"
#include "WebManager.h"
#include "ServoManager.h"

// ============================================================
//  TEST MODE
//    0 = full firmware (normal operation)
//    2 = Adafruit_ILI9341 display-only test (splash + RGB flash +
//        ID read). Kept for future hardware debugging — this is the
//        driver library DisplayManager now uses full-time, since
//        TFT_eSPI never got a response from this panel on this board.
// ============================================================
#define TEST_MODE 0

#if TEST_MODE == 2
#include <Adafruit_GFX.h>
#include <Adafruit_ILI9341.h>
#include <SPI.h>
#endif

// ============================================================
//  GLOBAL OBJECTS
// ============================================================

PIDController     pid;
PeltierControl    peltier;
TemperatureManager tempMgr;
RecipeManager     recipeMgr;
KeypadManager     keypadMgr;
DisplayManager    displayMgr;
AudioManager      audioMgr;
SafetyManager     safetyMgr;
WebManager        webMgr;
ServoManager      servoMgr;

// Helper to access underlying DFRobotDFPlayerMini reference for hmi_audio.h functions
inline DFRobotDFPlayerMini& getDFPlayer() {
    return audioMgr.dfPlayer();
}

SystemStatus      sysStatus;

// ============================================================
//  NON-BLOCKING TIMERS
// ============================================================

unsigned long lastDisplayUpdate = 0;
unsigned long lastPIDUpdate     = 0;
unsigned long lastSerialDebug   = 0;
unsigned long lastSafetyCheck   = 0;
unsigned long lastRampUpdate    = 0;

// Event-driven display watchdog:
//   displayCheckPending = true once, shortly after a step starts.
//   displayCheckAt      = millis() value at which to fire the one-shot check.
//   The periodic isAlive() poll was removed — it itself caused white-screen
//   flashes every 4 seconds due to ILI9341 SPI register reads mid-display.
bool          displayCheckPending = false;
unsigned long displayCheckAt      = 0;

// Unused — kept for backward compat with #define references in comments only
#define DISPLAY_HEALTH_CHECK_INTERVAL_MS  4000   // retained for reference
#define DISPLAY_HEALTH_FAIL_THRESHOLD     1       // immediate reinit on failure

// ============================================================
//  FORWARD DECLARATIONS
// ============================================================

void handleKeypress(char key);
void handleHomeKey(char key);
void handleMenuKey(char key);
void handleProgramKey(char key);
void handleStepEditKey(char key);
void handleConfirmStartKey(char key);
void handleConfirmStopKey(char key);
void handlePIDScreenKey(char key);
void handleCalibrationKey(char key);
void handleTestKey(char key);
void handleTestComponentKey(char key);
void handleAboutKey(char key);
void handleFaultKey(char key);
void handleCompleteKey(char key);
void handleStoppedKey(char key);
void handleManualPWMKey(char key);

void startProcess();
void handleWebCommand();
void stopProcess();
void advanceStep();
void enterApproachState();
void enterHoldState();
void enterRampState();
void completeProcess();

void updateApproachState();
void updateHoldState();
void updateRampState();

void serialDebugPrint();
void showScreen(ScreenID screen);

// ============================================================
//  HELPER — Temperature-scaled feedforward
// ============================================================
//  Wraps PIDController::computeFeedforward(). Defined here so it
//  is usable by enterApproachState, enterRampState, and updateRampState.
//  Formula: FF% = (25 − setpoint) / (25 − (−27)) × 100
//  Based on measured hardware: 12V/6.1V/2.45V → −27°C at 100% output.
inline float computeFF(float setpoint) {
    return PIDController::computeFeedforward(setpoint);
}

// ============================================================
//  SETUP
// ============================================================

#if TEST_MODE == 2
// ============================================================
//  ADAFRUIT_ILI9341 DISPLAY TEST — mirrors sih2026_input exactly
//  Same pins (CS=10, DC=9, RST=14, MOSI=11, SCK=12, MISO=13),
//  different driver library, to isolate library vs hardware.
// ============================================================
#define TEST2_MOSI 11
#define TEST2_SCK  12
#define TEST2_MISO 13
#define TEST2_CS   10
#define TEST2_DC    9
#define TEST2_RST  14

SPIClass tftSPI(FSPI);
Adafruit_ILI9341 adaTft(&tftSPI, TEST2_DC, TEST2_CS, TEST2_RST);

void setup() {
    Serial.begin(DEBUG_BAUD);
    delay(500);
    Serial.println();
    Serial.println("=== ADAFRUIT_ILI9341 DISPLAY TEST ===");
    Serial.printf("[TEST] MOSI=%d SCK=%d MISO=%d CS=%d DC=%d RST=%d\n",
                  TEST2_MOSI, TEST2_SCK, TEST2_MISO, TEST2_CS, TEST2_DC, TEST2_RST);

    tftSPI.begin(TEST2_SCK, TEST2_MISO, TEST2_MOSI, TEST2_CS);
    adaTft.begin();
    adaTft.setRotation(3);
    adaTft.fillScreen(ILI9341_BLACK);
    Serial.println("[TEST] adaTft.begin() returned.");

    uint8_t id1 = adaTft.readcommand8(0x04, 1);
    uint8_t id2 = adaTft.readcommand8(0x04, 2);
    uint8_t id3 = adaTft.readcommand8(0x04, 3);
    Serial.printf("[TEST] Display ID bytes (0x04): 0x%02X 0x%02X 0x%02X\n", id1, id2, id3);
    Serial.println("[TEST] ILI9341 should read approx: 0x00 0x93 0x41");
    if (id1 == 0x00 && id2 == 0x00 && id3 == 0x00) {
        Serial.println("[TEST] All zeros -> panel NOT responding even with Adafruit driver.");
    } else {
        Serial.println("[TEST] Got a non-trivial response -> panel IS responding to Adafruit driver!");
    }
}

void loop() {
    adaTft.fillScreen(ILI9341_RED);
    Serial.println("[TEST] RED");
    delay(1000);

    adaTft.fillScreen(ILI9341_GREEN);
    Serial.println("[TEST] GREEN");
    delay(1000);

    adaTft.fillScreen(ILI9341_BLUE);
    Serial.println("[TEST] BLUE");
    delay(1000);
}

#else
// ============================================================
//  FULL FIRMWARE setup()/loop() — active while TEST_MODE is 0
// ============================================================

void setup() {
    Serial.begin(DEBUG_BAUD);
    delay(500);

    Serial.println();
    Serial.println("============================================");
    Serial.println("  THULIR — 3-Stage Peltier Controller");
    Serial.printf("  Firmware v%s\n", FW_VERSION_STR);
    Serial.println("  ESP32-S3");
    Serial.println("============================================");
    Serial.println();
    Serial.println("POWER RESTORED — SYSTEM RESET");
    Serial.println("All Peltier outputs start at 0% (safe state)");
    Serial.println();

    // Initialize system status to safe defaults
    memset(&sysStatus, 0, sizeof(SystemStatus));
    sysStatus.state = STATE_BOOT;
    sysStatus.currentScreen = SCREEN_HOME;
    sysStatus.currentStep = 0;
    sysStatus.errorCode = ERROR_NONE;

    // --- Initialize peripherals ---

    // Display first (gives visual feedback during boot)
    Serial.println("[BOOT] Initializing TFT display...");
    displayMgr.begin();

    // Peltier drivers (all off by default)
    Serial.println("[BOOT] Initializing BTS7960 outputs...");
    peltier.begin();
    peltier.allPeltiersOff();  // Ensure safe state

    // Temperature sensor
    Serial.println("[BOOT] Initializing SHT3x sensor (temperature + humidity)...");
    bool sensorOK = tempMgr.begin();
    sysStatus.sensorValid = sensorOK;

    // Keypad
    Serial.println("[BOOT] Initializing keypad...");
    keypadMgr.begin();

    // Recipe (loads from NVS or creates defaults)
    Serial.println("[BOOT] Loading recipe from NVS...");
    recipeMgr.begin();

    // Load PID parameters from NVS
    float kp, ki, kd;
    recipeMgr.loadPIDParams(kp, ki, kd);
    pid.setTunings(kp, ki, kd);
    pid.setOutputLimits(PID_OUTPUT_MIN, PID_OUTPUT_MAX);
    pid.setSampleTime(PID_SAMPLE_TIME_MS);
    pid.setIntegralZone(APPROACH_INTEGRAL_ZONE);   // default to approach zone
    pid.setFeedforward(0.0f);                       // no FF until process starts
    pid.setRateLimit(PID_OUTPUT_RATE_LIMIT);
    Serial.printf("[BOOT] PID loaded: Kp=%.2f Ki=%.3f Kd=%.2f  FF=auto  Slew=%.0f%%/s\n",
                  kp, ki, kd, PID_OUTPUT_RATE_LIMIT);

    // Load calibration offset
    float calOffset = recipeMgr.loadCalibrationOffset();
    tempMgr.setCalibrationOffset(calOffset);
    Serial.printf("[BOOT] Calibration offset: %.2f °C\n", calOffset);

    // Load power ratios
    float botR, midR, topR;
    recipeMgr.loadPowerRatios(botR, midR, topR);
    peltier.setPowerRatios(botR, midR, topR);
    Serial.printf("[BOOT] Power ratios: BOT=%.0f%% MID=%.0f%% TOP=%.0f%%\n",
                  botR * 100.0f, midR * 100.0f, topR * 100.0f);

    // Audio (DFPlayer Mini)
    Serial.println("[BOOT] Initializing DFPlayer Mini...");
    audioMgr.begin();

    // Safety manager
    safetyMgr.begin();

    // Web dashboard telemetry (WiFi + HTTP POST, fully non-blocking to
    // control loop — see WebManager.h). Starts connecting in background;
    // does not delay boot even if WiFi/server unreachable.
    Serial.println("[BOOT] Starting web dashboard telemetry...");
    webMgr.begin();

    // Servo motors — initialise and open at boot
    Serial.println("[BOOT] Initializing servo motors...");
    servoMgr.begin();
    sysStatus.servosOpen          = true;
    sysStatus.servoStepTimerActive = false;
    sysStatus.servoStepOpenTime    = 0;

    // --- Boot complete ---
    Serial.println();
    Serial.println("[BOOT] ==============================");
    Serial.println("[BOOT]  THULIR BOOT COMPLETE");
    Serial.printf("[BOOT]  Sensor: %s\n", sensorOK ? "OK" : "ERROR");
    Serial.printf("[BOOT]  Audio:  %s\n", audioMgr.isAvailable() ? "OK" : "N/A");
    Serial.println("[BOOT] ==============================");
    Serial.println();

    // Transition to IDLE state
    sysStatus.state = STATE_IDLE;
    sysStatus.currentScreen = SCREEN_HOME;

    // Show initial home screen
    sysStatus.filteredTemp = tempMgr.getFilteredTemp();
    sysStatus.actualTemp = tempMgr.getRawTemp();
    showScreen(SCREEN_HOME);

    // Announce system start ("Welcome to THULIR CryoLab" - Track 7)
    audioMgr.announceWelcome();

    // If sensor failed at boot, show warning
    if (!sensorOK) {
        displayMgr.showMessage("SENSOR NOT FOUND!", COLOR_STATUS_ERR);
        Serial.println("[BOOT] WARNING: Temperature sensor not found at boot");
    }
}

// ============================================================
//  MAIN LOOP
// ============================================================

void loop() {
    unsigned long now = millis();

    // --- 1. Temperature sensor update (async, non-blocking) ---
    tempMgr.update();
    sysStatus.actualTemp = tempMgr.getRawTemp();
    sysStatus.filteredTemp = tempMgr.getFilteredTemp();
    sysStatus.sensorValid = tempMgr.isSensorValid();
    sysStatus.humidity = tempMgr.getHumidity();
    sysStatus.humidityValid = tempMgr.isHumidityValid();

    // --- 2. Keypad scan (non-blocking) ---
    char key = keypadMgr.update();
    if (key) {
        handleKeypress(key);
    }

    // --- 3. PID control (time-gated) ---
    if (sysStatus.state == STATE_STEP_APPROACH ||
        sysStatus.state == STATE_STEP_HOLD ||
        sysStatus.state == STATE_STEP5_RAMP) {

        if (pid.compute(sysStatus.currentSetpoint, sysStatus.filteredTemp)) {
            sysStatus.pidOutput = pid.getOutput();
            peltier.setCascadePower(sysStatus.pidOutput, sysStatus);
        }
    }

    // --- 4. State-specific updates ---
    switch (sysStatus.state) {
        case STATE_STEP_APPROACH:
            updateApproachState();
            break;

        case STATE_STEP_HOLD:
            updateHoldState();
            break;

        case STATE_STEP5_RAMP:
            updateRampState();
            break;

        default:
            break;
    }

    // --- 5. Safety checks (time-gated) ---
    if ((now - lastSafetyCheck) >= SAFETY_CHECK_INTERVAL) {
        bool wasActive = (sysStatus.state == STATE_STEP_APPROACH ||
                          sysStatus.state == STATE_STEP_HOLD    ||
                          sysStatus.state == STATE_STEP5_RAMP   ||
                          sysStatus.state == STATE_STEP_TRANSITION);
        safetyMgr.update(tempMgr, peltier, audioMgr, sysStatus);
        // If the safety manager just transitioned us into FAULT, open servos
        if (wasActive && sysStatus.state == STATE_FAULT) {
            servoMgr.openServos();
            sysStatus.servoStepTimerActive = false;
            Serial.println("[SERVO] Opened on safety fault");
            showScreen(SCREEN_FAULT);
        }
        lastSafetyCheck = now;
    }

    // --- 6. Audio update (non-blocking) ---
    audioMgr.update();

    // --- 6b. Web dashboard telemetry (non-blocking, self-paced) ---
    {   // publish the recipe in effect so the dashboard profile matches the device
        const Recipe& rc = recipeMgr.getRecipe();
        for (uint8_t i = 0; i < 4; i++) sysStatus.recipeHold[i] = rc.steps[i].holdTimeMin;
        sysStatus.recipeT2 = rc.steps[1].targetTemp;
        sysStatus.recipeT4 = rc.steps[3].targetTemp;
    }
    webMgr.update(sysStatus);

    // --- 6b'. Remote command from the dashboard (START / ABORT) ---
    handleWebCommand();

    // --- 6c. Servo update (manages timed step-open window) ---
    servoMgr.update(sysStatus);

    // --- 7. Display update (time-gated) ---
    if ((now - lastDisplayUpdate) >= DISPLAY_UPDATE_INTERVAL) {
        if (sysStatus.currentScreen == SCREEN_HOME) {
            displayMgr.updateHomeScreen(sysStatus);
        } else if (sysStatus.currentScreen == SCREEN_PID) {
            displayMgr.updatePIDScreen(
                pid.getKp(), pid.getKi(), pid.getKd(),
                sysStatus.filteredTemp, sysStatus.currentSetpoint,
                sysStatus.pidOutput,
                pid.getPterm(), pid.getIterm(), pid.getDterm()
            );
        }
        lastDisplayUpdate = now;
    }

    // --- 7b. Display watchdog (EVENT-DRIVEN — one-shot post-start check) ---
    //  The periodic isAlive() poll was removed because the SPI register read
    //  that isAlive() performs itself caused the display to flash white every
    //  4 seconds. Instead, a one-shot check fires ~4 seconds after each step
    //  transition (when the 12V system starts heavy switching — the most
    //  likely moment for a RST-line noise glitch). If that single check finds
    //  the display unresponsive it reinitialises immediately. Otherwise the
    //  watchdog is silent until the next step transition schedules a new check.
    if (displayCheckPending && (now >= displayCheckAt)) {
        displayCheckPending = false;
        if (!displayMgr.isAlive()) {
            Serial.println("[DISPLAY] Post-start check failed — reinitialising");
            displayMgr.begin(false);               // silent recovery (no splash)
            showScreen(sysStatus.currentScreen);   // redraw current screen
        } else {
            Serial.println("[DISPLAY] Post-start check OK");
        }
    }

    // --- 8. Serial debug (time-gated) ---
    #if DEBUG_ENABLED
        if ((now - lastSerialDebug) >= SERIAL_PRINT_INTERVAL) {
            serialDebugPrint();
            lastSerialDebug = now;
        }
    #endif
}

#endif // TEST_MODE

// ============================================================
//  KEYPRESS ROUTING
// ============================================================

void handleKeypress(char key) {
    // Emergency stop: C key during an active process, from ANY screen —
    // must not require navigating back to HOME first.
    if (key == KEY_BACK &&
        sysStatus.currentScreen != SCREEN_CONFIRM_STOP &&
        (sysStatus.state == STATE_STEP_APPROACH ||
         sysStatus.state == STATE_STEP_HOLD ||
         sysStatus.state == STATE_STEP_TRANSITION ||
         sysStatus.state == STATE_STEP5_RAMP)) {
        showScreen(SCREEN_CONFIRM_STOP);
        return;
    }

    switch (sysStatus.currentScreen) {
        case SCREEN_HOME:           handleHomeKey(key); break;
        case SCREEN_MENU:           handleMenuKey(key); break;
        case SCREEN_PROGRAM:        handleProgramKey(key); break;
        case SCREEN_STEP_EDIT:      handleStepEditKey(key); break;
        case SCREEN_CONFIRM_START:  handleConfirmStartKey(key); break;
        case SCREEN_CONFIRM_STOP:   handleConfirmStopKey(key); break;
        case SCREEN_PID:            handlePIDScreenKey(key); break;
        case SCREEN_CALIBRATION:    handleCalibrationKey(key); break;
        case SCREEN_TEST:           handleTestKey(key); break;
        case SCREEN_TEST_COMPONENT: handleTestComponentKey(key); break;
        case SCREEN_ABOUT:          handleAboutKey(key); break;
        case SCREEN_FAULT:          handleFaultKey(key); break;
        case SCREEN_COMPLETE:       handleCompleteKey(key); break;
        case SCREEN_STOPPED:        handleStoppedKey(key); break;
        case SCREEN_MANUAL_PWM:     handleManualPWMKey(key); break;
        default: break;
    }
}

// --- HOME SCREEN ---
void handleHomeKey(char key) {
    if (key == KEY_ENTER) {
        // Open main menu
        sysStatus.menuSelection = 0;
        showScreen(SCREEN_MENU);
    }
}

// --- MENU SCREEN ---
void handleMenuKey(char key) {
    if (key == KEY_UP) {
        if (sysStatus.menuSelection > 0) sysStatus.menuSelection--;
        showScreen(SCREEN_MENU);
    }
    else if (key == KEY_DOWN) {
        if (sysStatus.menuSelection < MENU_ITEM_COUNT - 1) sysStatus.menuSelection++;
        showScreen(SCREEN_MENU);
    }
    else if (key == KEY_ENTER) {
        switch ((MenuItemID)sysStatus.menuSelection) {
            case MENU_PROGRAM:
                sysStatus.editStep = 0;
                showScreen(SCREEN_PROGRAM);
                break;
            case MENU_START:
                if (sysStatus.state == STATE_IDLE || sysStatus.state == STATE_READY) {
                    showScreen(SCREEN_CONFIRM_START);
                } else {
                    displayMgr.showMessage("Cannot start: process active", COLOR_STATUS_WARN);
                }
                break;
            case MENU_STOP:
                if (sysStatus.state == STATE_STEP_APPROACH ||
                    sysStatus.state == STATE_STEP_HOLD ||
                    sysStatus.state == STATE_STEP5_RAMP) {
                    showScreen(SCREEN_CONFIRM_STOP);
                } else {
                    displayMgr.showMessage("No active process to stop", COLOR_TEXT_DIM);
                }
                break;
            case MENU_SETTINGS:
                // Future: settings submenu
                displayMgr.showMessage("Settings: Use PID/CAL screens", COLOR_TEXT_DIM);
                break;
            case MENU_PID_TUNE:
                showScreen(SCREEN_PID);
                break;
            case MENU_TEST_MODE:
                showScreen(SCREEN_TEST);
                break;
            case MENU_ABOUT:
                showScreen(SCREEN_ABOUT);
                break;
        }
    }
    else if (key == KEY_BACK) {
        showScreen(SCREEN_HOME);
    }
}

// --- PROGRAM SCREEN ---
void handleProgramKey(char key) {
    if (key == KEY_UP) {
        if (sysStatus.editStep > 0) sysStatus.editStep--;
        showScreen(SCREEN_PROGRAM);
    }
    else if (key == KEY_DOWN) {
        if (sysStatus.editStep < 3) sysStatus.editStep++;  // Steps 1-4 editable
        showScreen(SCREEN_PROGRAM);
    }
    else if (key == KEY_ENTER) {
        // Edit selected step & announce wizard duration prompt (Tracks 8-11)
        showScreen(SCREEN_STEP_EDIT);
        audioMgr.announceWizard(sysStatus.editStep + 1);
    }
    else if (key == KEY_CONFIRM) {
        // Save recipe to NVS
        recipeMgr.saveToNVS();
        displayMgr.showMessage("RECIPE SAVED!", COLOR_STATUS_OK);
        sysStatus.state = STATE_READY;
    }
    else if (key == KEY_BACK) {
        showScreen(SCREEN_MENU);
    }
}
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

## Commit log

2026-09-17 feat: add initial source files and core modules for thulir_final Arduino project
2026-09-19 refactor: migrate display to TFT_eSPI library, reallocate GPIO pins for SPI, and adapt Peltier PWM for Core 2.x
2026-09-19 refactor: switch display driver from TFT_eSPI to Adafruit_ILI9341 and update hardware pin mappings
2026-09-19 feat: add safety features including ramp timeout, cold-side sanity checks, temperature jump filtering, and deferred audio playback
2026-09-19 refactor: replace cold-side DS18B20 sensor with SHT3x temperature and humidity sensor
    [Config.h, DisplayManager.cpp, TemperatureManager.cpp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]
2026-09-19 fix: reassign SHT3x I2C pins to GPIO 35/36 and update humidity display layout
    [Config.h, DisplayManager.cpp]
2026-09-20 feat: add PID integral separation and display watchdog for noise recovery
    [Config.h, DisplayManager.cpp, thulir_final.ino]
2026-09-20 feat: enhance PID controller with feedforward control, output slew-rate limiting, and configurable integral zones
2026-09-20 refactor: replace temp shortcuts with A/B cycling, enable direct numeric input, and switch to event-driven display watchdog
    [DisplayManager.cpp, thulir_final.ino]
2026-09-20 fix: add missing closing brace in display check
    [thulir_final.ino]
2026-09-20 refactor: restructure audio management and update track mappings with new hmi_audio header
2026-10-08 feat: implement thulir control firmware with servo management and telemetry web dashboard
    [Cryo Unit.step, cooling_unit.kicad_pcb, cooling_unit.kicad_sch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]
2026-10-09 feat: add web dashboard, remote control commands, and UI assets
    [bot.kicad_pcb, bot.kicad_sch]
2026-10-10 feat: add DS18B20 cold-side temperature sensor support and dashboard backend integration
2026-10-10 feat: add Peltier minimum temperature test sketch and update pin configurations in Config.h
2026-10-10 refactor: update PID feedforward, power ratios, and add Peltier min-temp test sketch
2026-10-10 feat: add standalone Peltier minimum temperature test script
2026-10-11 feat: add final 3D assembly STEP model file
2026-10-11 feat: add standalone Peltier minimum temperature test firmware
2026-10-13 fix: correct ESP32-S3 LEDC resolution to 14 bits, update servo pin configuration, and close lid on process start
2026-10-15 refactor: migrate servo control from direct GPIO LEDC to PCA9685 I2C driver
